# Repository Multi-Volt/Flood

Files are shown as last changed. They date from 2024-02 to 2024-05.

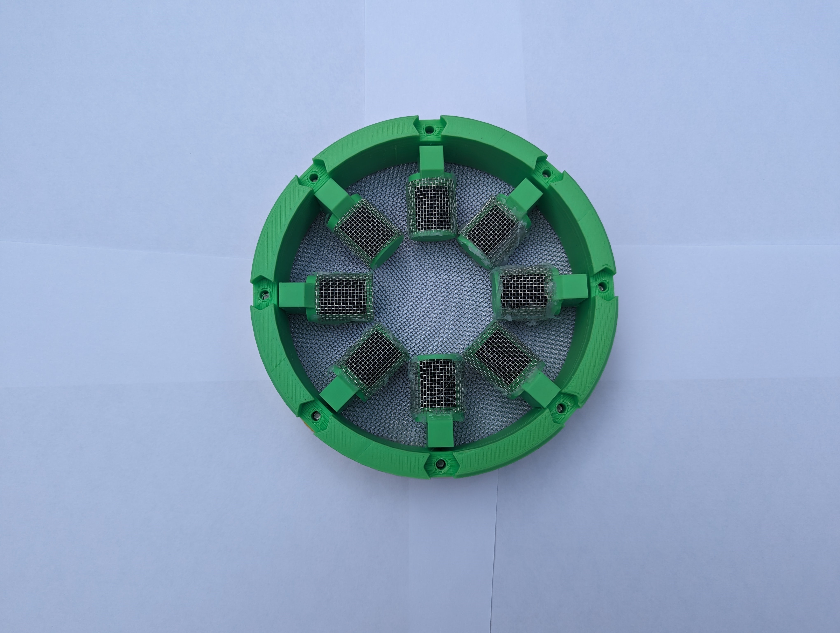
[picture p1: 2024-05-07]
FLOOD-Photos/Control/DesTopWheel.jpg

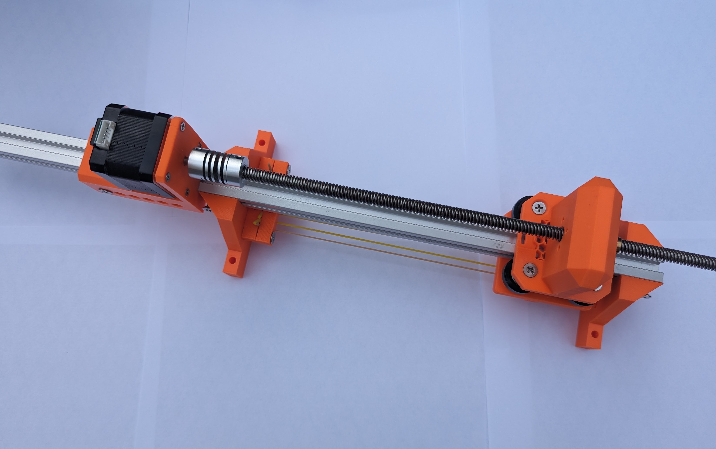
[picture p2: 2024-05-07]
FLOOD-Photos/Proto/NiTiTopView.jpg

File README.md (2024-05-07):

# Flood

[![Platform Io](https://img.shields.io/badge/build%20with-PlatformIO-orange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)](https://platformio.org/)

This research endeavor, conducted by __Dr. John LaRocco__, __Dr. Qudsia Tahmina__, and __John Simonis__ at The Ohio State University, is dedicated to the development of an Elastocaloric atmospheric water harvester. Specifically, the primary objective of this project is to construct a system that can be juxtaposed with a conventional desiccant wheel system for the purpose of energy efficient water harvesting. Included in this repository is the evaluation of the efficiency and effectiveness of the newly developed system in comparison to its traditional counterpart. This project is a significant and novel step towards innovative solutions in the field of water harvesting technology.
## Requirements
### Software
- [VSCode](https://code.visualstudio.com/Download)
- [Platform IO](https://platformio.org/)
- [Git](https://git-scm.com/downloads)
- [Arduino IDE](https://www.arduino.cc/en/software)
- [PySR](https://github.com/MilesCranmer/PySR)
- [PrusaSlicer]( https://www.prusa3d.com/en/page/prusaslicer_424/) or other slicer
### Hardware
- [FLOOD-BOM](https://github.com/Multi-Volt/Flood/tree/main/FLOOD-BOM/)
- 3D-Printer
- Screw Driver
# Table of contents
- [Models & Construction](#models)
- [Data](#data)
- [Datalogger](#datalogger)
- [Testing](#testing)
- [Flood Equations](#flood-equations)
- [Flood MCU](#flood-mcu)
- [Flood Photos](#flood-photos)
- [License](#license)
## Models & Construction
For this project, all pertinent 3D models are housed in the [FLOOD-3DF](https://github.com/Multi-Volt/Flood/tree/main/FLOOD-3DF) directory. This directory is organized into the following sub-directories for ease of navigation and access:
1. **Proto**: This contains both STEP and STL files of the final prototype.
2. **Control**: This includes the STEP and STL files for the Control Harvester.
3. **Deprecated**: This houses the STL files of designs that are no longer in use.
### Details
**Control Water Harvester Assembly Overview and Instructions**

The Control Water Harvester utilizes a desiccant wheel design, leveraging a heat lamp to dry out pockets of desiccant and a fan to circulate heated air through the silica gel desiccant. The assembly process is as follows:
1. **File Download**: Retrieve the STL files from [FLOOD-3DF](https://github.com/Multi-Volt/Flood/tree/main/FLOOD-3DF) and the .3MF file if you plan to print the design on a standard Ender 3 PRO.
2. **Setup**: Import the model or .3MF into an FDM 3D-Printer slicer such as [PrusaSlicer]( https://www.prusa3d.com/en/page/prusaslicer_424/) and select a material profile for PETG, which is necessary for higher temperatures.
3. **Slicing**: Configure a print with one wheel base and eight wheel rungs. Ensure the slicing settings include 100% infill, supports everywhere, and a layer height of 0.16mm or lower. Refer to the .3MF file for printing orientations
4. **Assembly**: Connect each of the rungs to the wheel base and secure each with M5 bolts and nuts, as specified in the Bill of Materials (BOM).
5. **Testing**: Upon completion of assembly, conduct a test using a lab power supply. Ensure the availability of fans and a heating device.

**NiTi Prototype Assembly Instructions**

The NiTi prototype employs a straightforward gantry system, powered by a high torque stepper motor. A T8 leadscrew is incorporated for a simple mechanical advantage to apply stress to the NiTi wires. The assembly process is as follows:
1. **File Download**: Retrieve the STL files from [FLOOD-3DF](https://github.com/Multi-Volt/Flood/tree/main/FLOOD-3DF) and the .3MF file if you plan to print the design on a standard Ender 3 PRO.
2. **Setup**: Import the model or .3MF into an FDM 3D-Printer slicer such as [PrusaSlicer]( https://www.prusa3d.com/en/page/prusaslicer_424/). Select a material profile for PETG, which is necessary for higher temperatures.
3. **Slicing**: Configure a print with one of each part, except for the anchors, of which you should print two. Ensure the slicing settings include 100% infill, supports everywhere, and a layer height of 0.16mm or lower. Refer to the .3MF file for printing orientations
4. **Nut Selection**: Based on the dimensions of most of the nut pockets, identify suitable metric nuts.
5. **Assembly**: Secure each of the items in accordance with the provided render.
6. **Gantry Fastening**: Ensure the use of the appropriate metric T-nuts for fastening to the supplied gantry.
7. **Testing**: Upon completion of the mechanical assembly, refer to the wiring diagram provided below and prepare for testing. You will need to either develop your own code for controlling the motors or utilize the open-source [GRBL](https://github.com/grbl/grbl) firmware.

[(Back to top)](#table-of-contents)
### Wiring

**Control Water Harvester**

The control water harvester uses one PC fan and a generic ~150-watt heat lamp. It is mounted to a piece of wood and turns with heated air blowing through each rung filled with desiccant on the wheel. For an example setup please see [FLOOD-Photos](https://github.com/Multi-Volt/Flood/tree/main/FLOOD-Photos). Water recorded was done using the sensor setup found in [FLOOD-Schematics](https://github.com/Multi-Volt/Flood/tree/main/FLOOD-Schematics).

**NiTi Water Harvester**

The NiTi water harvester uses a generic 8-amp DC barrel jack power supply. It can be mounted to a piece of wood and during testing was controlled with an Atmega328p microcontroller running the [GRBL](https://github.com/grbl/grbl) firmware. For an example setup please see [FLOOD-Photos](https://github.com/Multi-Volt/Flood/tree/main/FLOOD-Photos). Water recorded was done using the sensor setup found in [FLOOD-Schematics](https://github.com/Multi-Volt/Flood/tree/main/FLOOD-Schematics).

[(Back to top)](#table-of-contents)
## Data
Currently, all data for this project can be found within the [FLOOD-Data](https://github.com/Multi-Volt/Flood/tree/main/FLOOD-Data) folder. This folder currently contains:
- Control (XLSX)
- Prototype (XLSX)
- Analysis ([Jupyter Notebook](https://jupyter.org/))

[(Back to top)](#table-of-contents)
## Datalogger
This project currently uses a compiled Datalogger from a previous research project from this team. Currently, this binary is only compiled for Windows systems and is present within the [FLOOD-Datalogger](https://github.com/Multi-Volt/Flood/tree/main/FLOOD-Datalogger) folder.

[(Back to top)](#table-of-contents)
## Testing
**Project Testing Procedure**

The testing procedure for this project was executed with a straightforward approach. The following steps were undertaken:
- **Assemblies**: Both the prototype and control assemblies were positioned within an enclosure equipped with a continuously operating humidifier.
- **Data Gathering**: Data was systematically collected at regular intervals of 10 seconds. Measurements, such as current, were averaged over this time frame.
- **Noise Reduction**: The averaging of measurements over the specified time frame was implemented to effectively mitigate the impact of noise and potential outliers.
- **Execution**: A total of three tests were conducted for both the control and the prototype assemblies.
- **Duration**: The entire testing procedure was carried out over a cumulative duration of 30 minutes.
- **Water Sensor**: The resistive water sensor was calibrated using a control amount of water for precision before any water was harvested.
This methodical approach ensured a comprehensive evaluation of the project components under the specified conditions.

[(Back to top)](#table-of-contents)
## Flood Equations
These are equations fitted to the averaged data of each water harvester design. These equations were fitted using PySR and were designed to minimize the MSE between the two equations, if the Jupyter notebook file present in [FLOOD-Data](https://github.com/Multi-Volt/Flood/tree/main/FLOOD-Data/Analysis) is run again, each would have different results.

MSE:
```math
\text{MSE}=\frac{1}{n}\sum_{i=1}^{n}(f(x)-g(x))^{2}
```
Desiccant Control Wheel:
```math
\log{\left(1.18^{x + 0.841 \cos{\left(x^{0.974} + 0.155 \right)} + \cos{\left(\left\lceil{x}\right\rceil^{0.553} \right)} \left\lfloor{e^{\text{erf}{\left(x \right)}}}\right\rfloor} + 0.550 x \right)}
```
```math
\text{MSE}=2.695e-02
```
NiTi Prototype:
```math
x \left(- 0.000675 x - 0.00581 \cos{\left(0.861 \text{erf}{\left(\cos{\left(0.632 x \right)} \right)} + 0.861 \left\lfloor{x - 0.855}\right\rfloor \right)} + 0.214\right)
```
```math
\text{MSE}=2.507e-02
```
Deprecated Control:
```math
\left\lceil{\log{\left(0.526 x + 2.07 \right)}}\right\rceil \text{erf}{\left(0.0790 x + 0.0790 \sin{\left(0.0924 x \left\lfloor{x + \sin{\left(x \cos{\left(\cos{\left(\text{erf}{\left(\cos{\left(\left(e^{x} + 2.07\right) \left\lceil{\cos{\left(2 e^{\left\lceil{x}\right\rceil + 1} \right)}}\right\rceil \right)} \right)} \right)} \right)} \right)}}\right\rfloor \right)} \right)}
```
```math
\text{MSE}=8.403e-03
```
Deprecated Prototype:
```math
\log{\left(1.08^{x + 2.39 e^{\sin{\left(x + 0.573 \right)}}} \text{erf}{\left(\sin{\left(\text{erf}{\left(\cos{\left(1.07^{\left\lceil{x + 1.00 \cos{\left(x + 0.771 \right)} + 0.349}\right\rceil} \right)} \right)} \right)} \right)} + 1.14^{x} \right)}^{0.720}
```
```math
\text{MSE}=1.869e-02
```

## Flood MCU
**Instructions for Opening and Building MCU Code**

1. **Install Visual Studio Code (VS Code)**: Ensure that you have VS Code installed on your system as per the prerequisites mentioned earlier.
2. **Install Platform IO**: After successfully installing VS Code, proceed to install Platform IO.
3. **Download the Platform IO Directory**: Once Platform IO is installed, download the Platform IO directory from the [FLOOD-MCU](https://github.com/Multi-Volt/Flood/tree/main/FLOOD-MCU) folder.
4. **Open the Platform IO Directory in VS Code**: After downloading the files, open the directory in VS Code.
5. **Navigate to the Platform IO Extension**: Within VS Code, navigate to the Platform IO extension.
6. **Select the Folder**: From the Platform IO extension, choose the 'Pick a folder' option and select the folder that contains the `platformio.ini` file.
7. **Access the main.cpp Program**: You can now access the `main.cpp` program located in the `src` directory.
8. **Ensure Arduino Nano or Uno is Plugged In**: To access automatic build deployment, ensure that an Arduino Nano or Arduino Uno is plugged into your system.

[(Back to top)](#table-of-contents)
## Flood Photos
For this project, all pertinent images are housed in the [FLOOD-PHOTOS](https://github.com/Multi-Volt/Flood/tree/main/FLOOD-PHOTOS) directory. This directory is organized into the following sub-directories for ease of navigation and access:
1. **Proto**: This contains images for the final prototype.
2. **Control**: This includes images for the Control Harvester.
3. **Deprecated**: This houses the images for designs that are no longer in use.
# License
The MIT License (MIT) 2024 - [Dr. John LaRocco](https://github.com/javeharron/), [Dr. Qudsia Tahmina](https://github.com/tahminaq), [John Simonis](https://github.com/Multi-Volt/). Please have a look at the [LICENSE.md](LICENSE) for more details.

[(Back to top)](#table-of-contents)

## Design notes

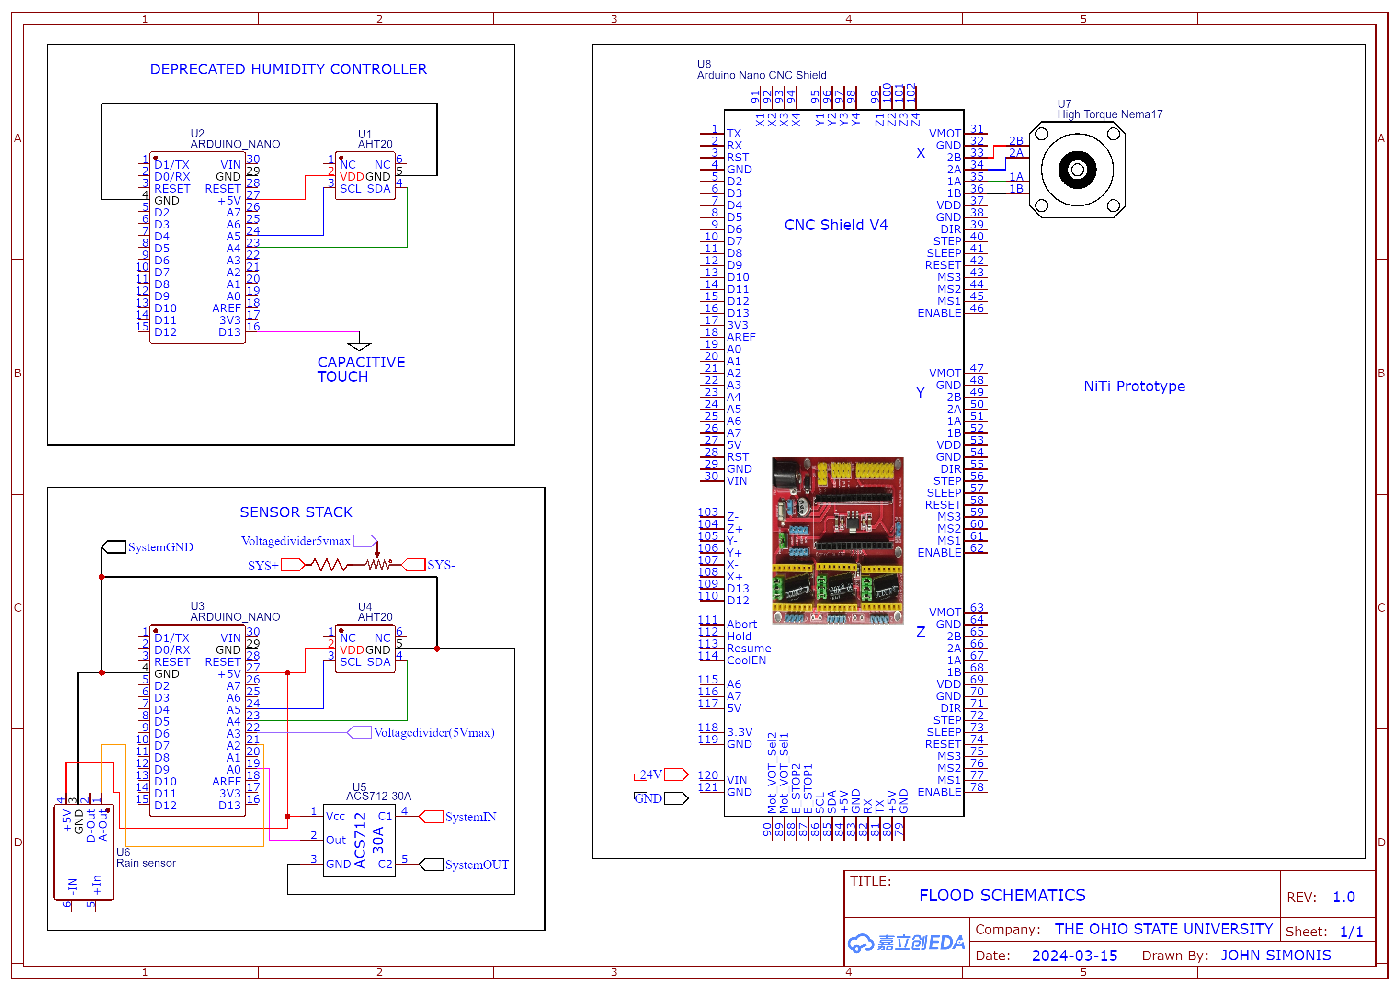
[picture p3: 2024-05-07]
FLOOD-Schematics/Schematics.png

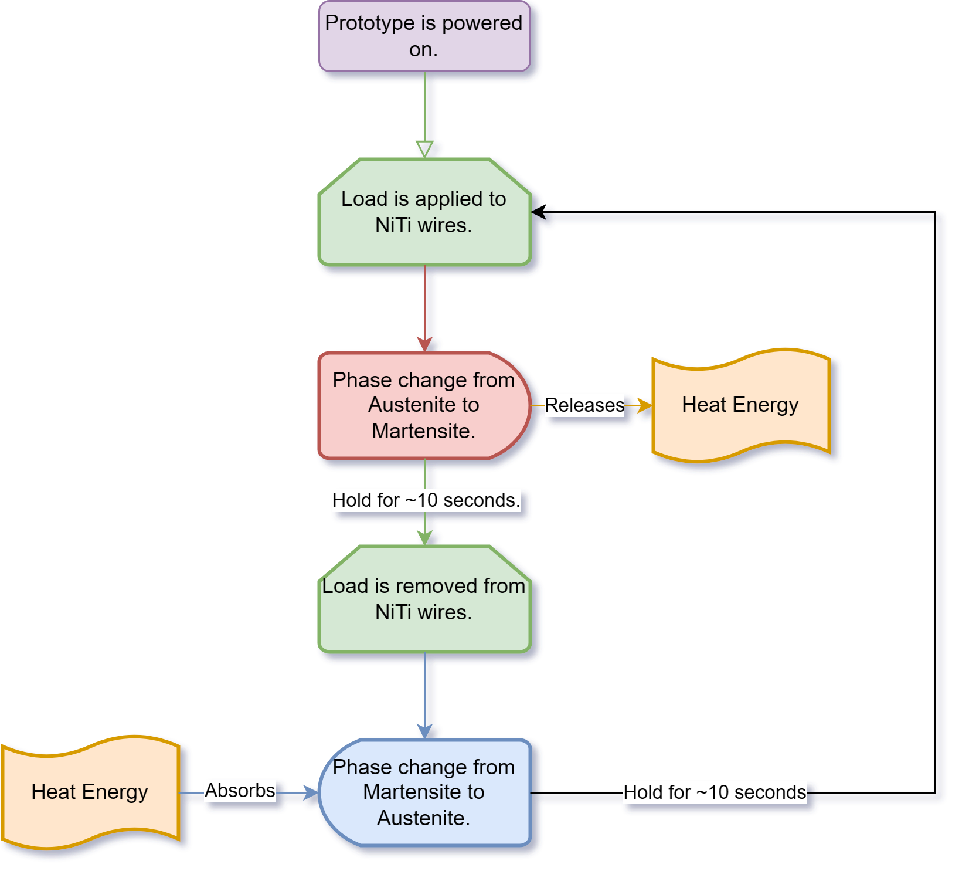
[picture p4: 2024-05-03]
FLOOD-Photos/Nitinol Process.png

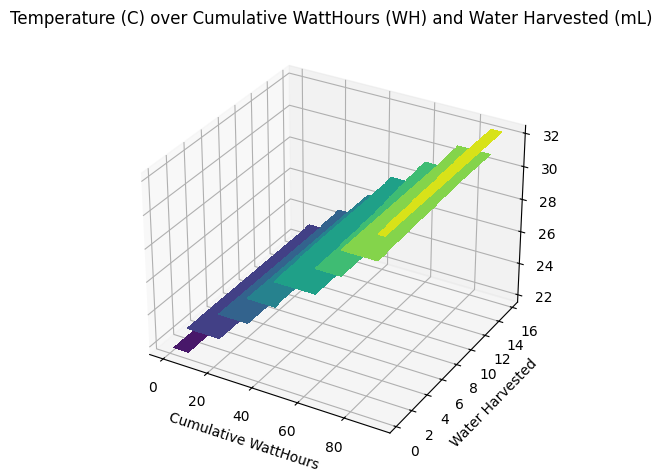
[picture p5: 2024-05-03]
FLOOD-Photos/Control/DesControlContour.png

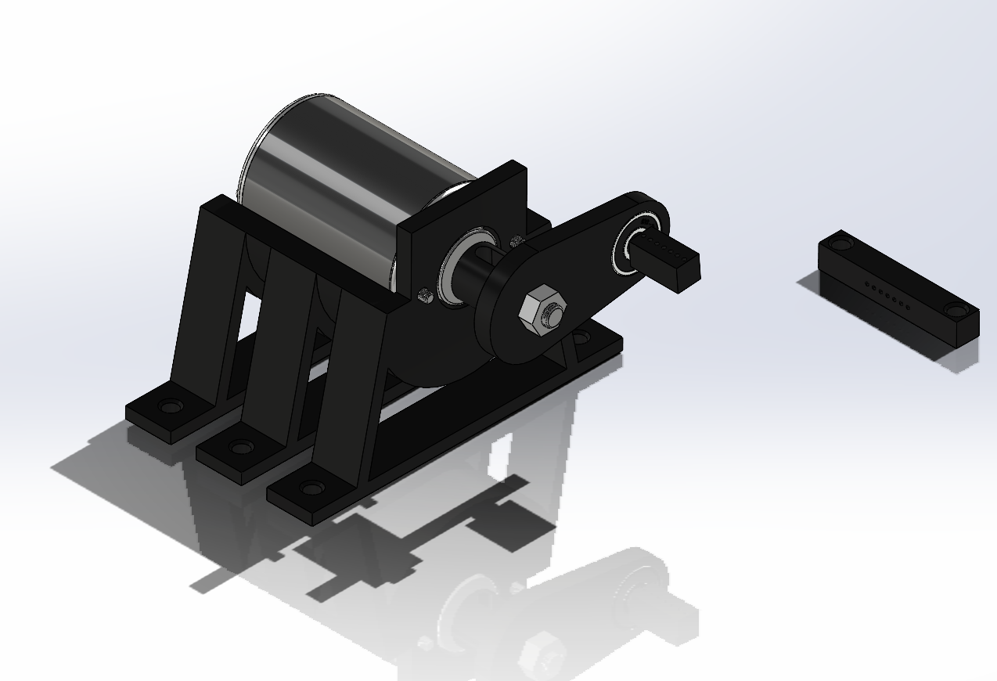
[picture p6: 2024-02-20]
FLOOD-Photos/Proto1_Render.png

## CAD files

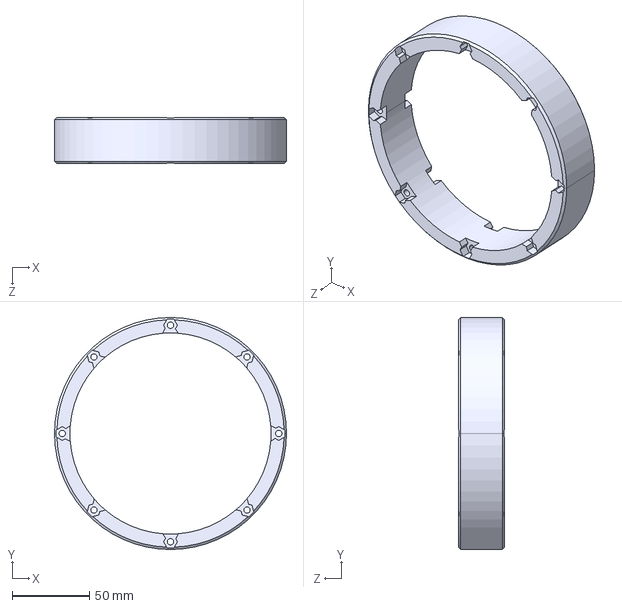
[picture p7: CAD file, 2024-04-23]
FLOOD-3DF/Control/CAD/CentralRing.STEP
150.0 x 150.0 x 30.0 mm

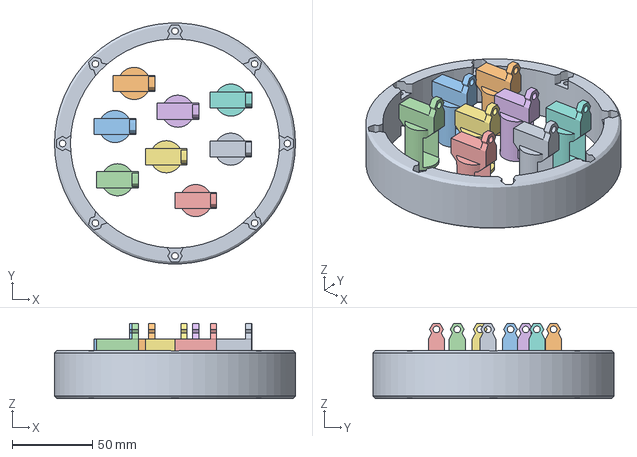
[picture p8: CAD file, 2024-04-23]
FLOOD-3DF/Control/Ender3_ControlPrintFile.3mf
150.0 x 149.8 x 46.8 mm
CentralRing.STL
WheelRung.STL x 8

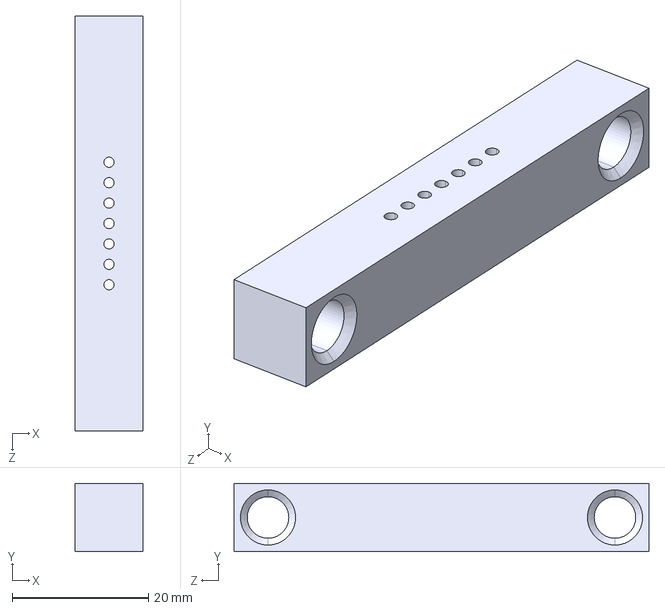
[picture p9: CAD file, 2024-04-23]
FLOOD-3DF/Proto/CAD/StaticAnchor.STEP
10.0 x 10.0 x 61.0 mm

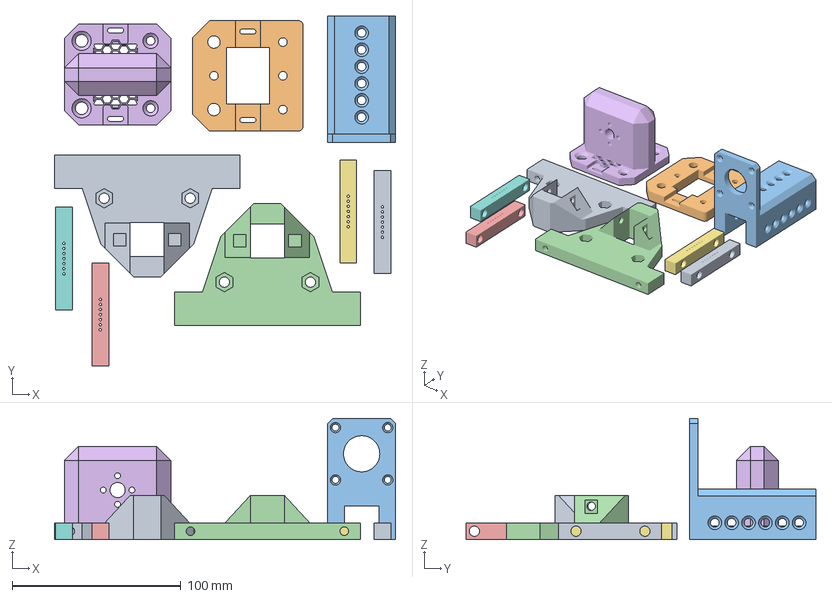
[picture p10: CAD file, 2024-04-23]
FLOOD-3DF/Proto/Ender3_ProtoPrintFile.3mf
202.4 x 207.5 x 71.9 mm
CarriageAnchor.STL x 2
CarriageSupportBracket.STL
MotorMount.STL
Stand.STL x 2
StaticAnchor.STL x 2
WheelCarriage.STL

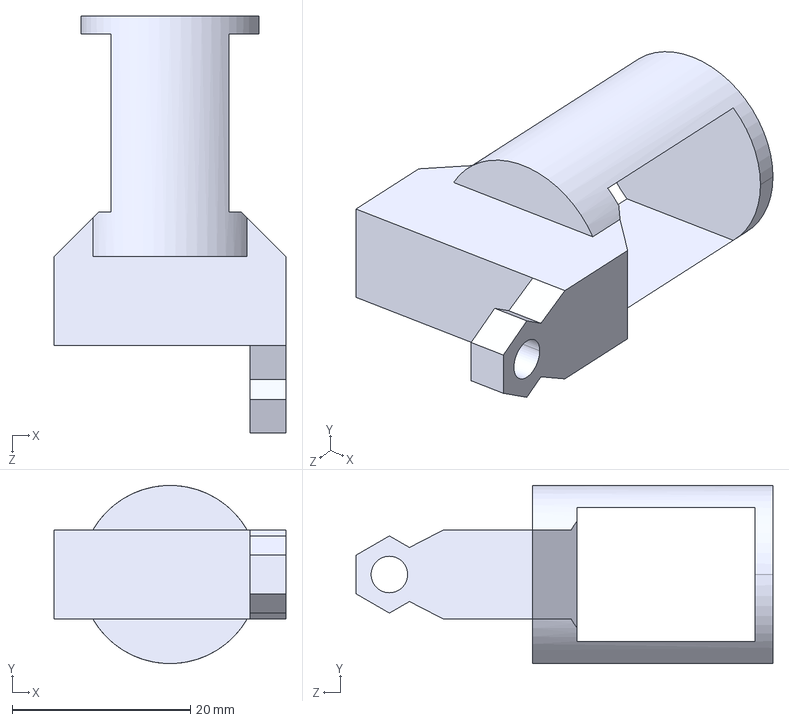
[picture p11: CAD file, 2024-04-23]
FLOOD-3DF/Control/CAD/WheelRung.STEP
26.0 x 20.0 x 46.8 mm

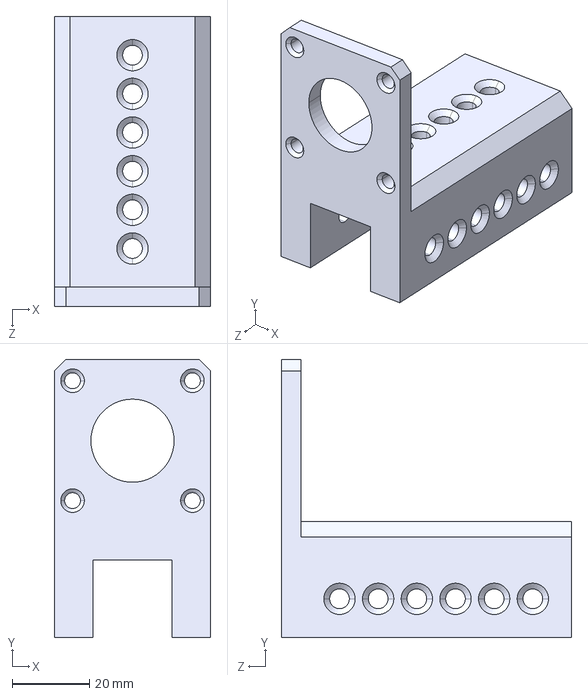
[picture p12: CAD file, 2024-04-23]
FLOOD-3DF/Proto/CAD/MotorMount.STEP
40.4 x 71.9 x 75.0 mm

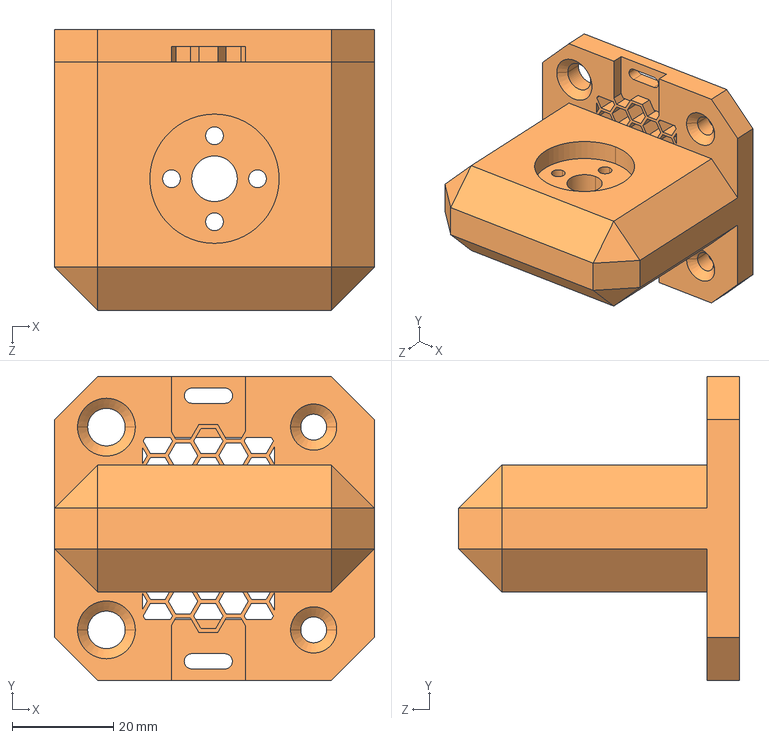
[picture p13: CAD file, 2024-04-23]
FLOOD-3DF/Proto/CAD/WheelCarriage.STEP
63.1 x 60.0 x 55.4 mm

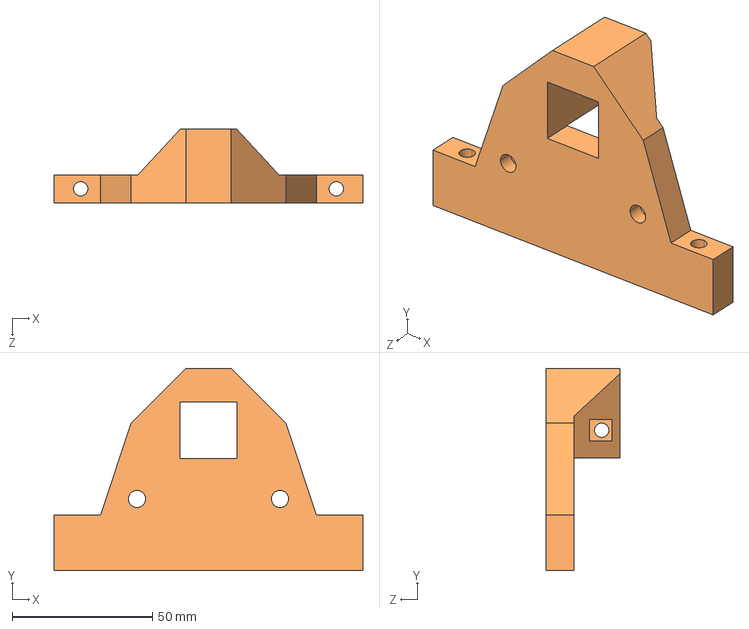
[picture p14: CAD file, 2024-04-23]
FLOOD-3DF/Proto/CAD/Stand.STEP
110.2 x 72.2 x 26.3 mm

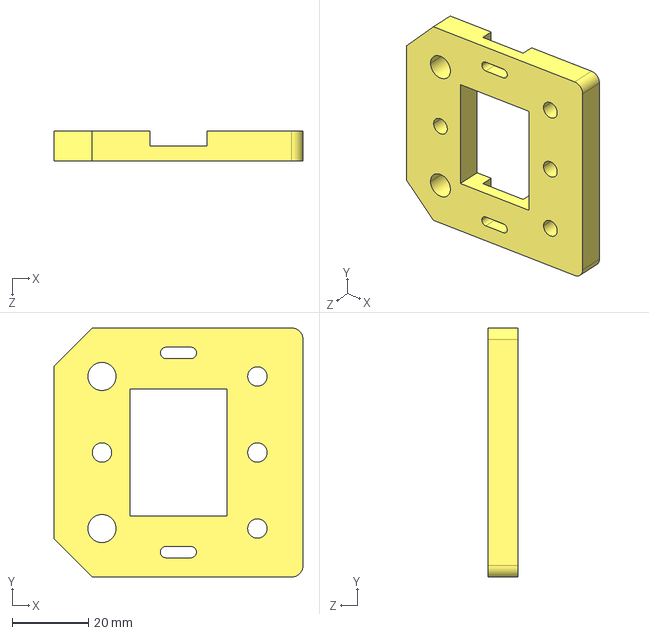
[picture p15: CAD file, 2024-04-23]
FLOOD-3DF/Proto/CAD/CarriageSupportBracket.STEP
65.5 x 65.5 x 8.00 mm

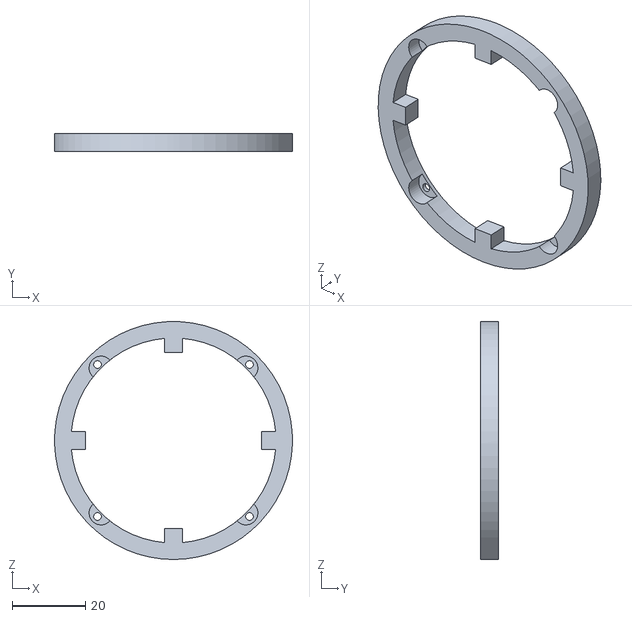
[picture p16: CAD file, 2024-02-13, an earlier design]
FLOOD-3DF/Deprecated/Control/Control_LidBracket.STL
65.0 x 5.00 x 65.0

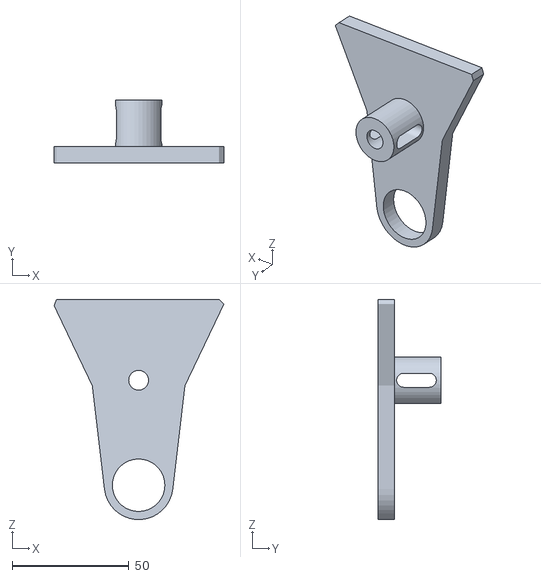
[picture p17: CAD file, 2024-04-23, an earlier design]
FLOOD-3DF/Deprecated/Prototype1_Rev2/Proto1_Cam.STL
72.7 x 27.0 x 94.3

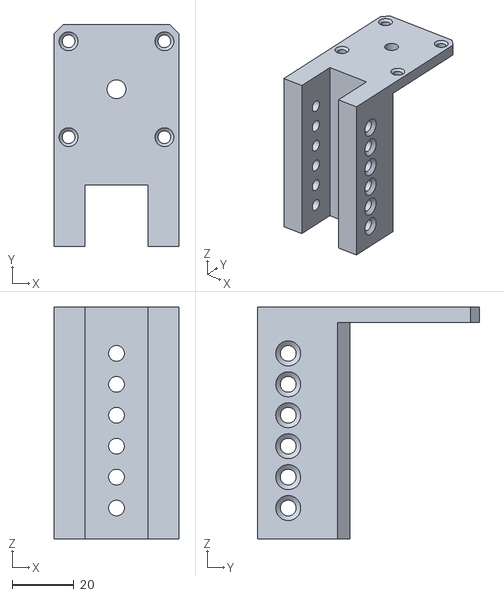
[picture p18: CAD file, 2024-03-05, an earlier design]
FLOOD-3DF/Deprecated/Prototype2/Proto2_MotorMount.STL
40.4 x 71.9 x 75.0

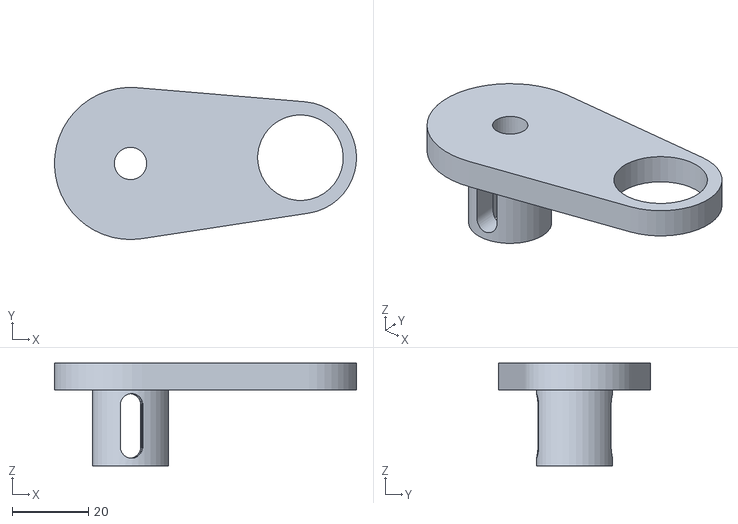
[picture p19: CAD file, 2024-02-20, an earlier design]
FLOOD-3DF/Deprecated/Prototype1_Rev1/Proto1_Cam.STL
79.4 x 40.0 x 27.0

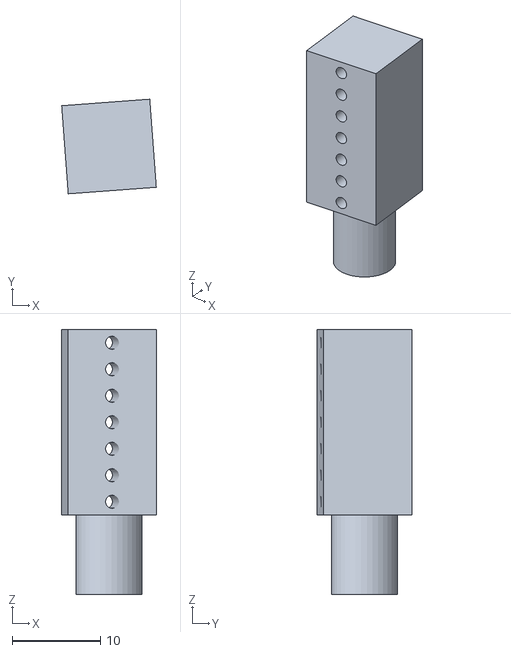
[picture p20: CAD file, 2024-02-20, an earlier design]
FLOOD-3DF/Deprecated/Prototype1_Rev2/Proto1_CamArm.STL
10.7 x 10.7 x 30.0

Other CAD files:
FLOOD-3DF/Proto/CAD/CarriageAnchor.STEP
FLOOD-3DF/Deprecated/Prototype1_Rev1/Proto1_StaticAnchor.STL
FLOOD-3DF/Deprecated/Prototype2/Proto2_CarriageTop.STL
FLOOD-3DF/Control/STL/CentralRing.STL
FLOOD-3DF/Control/STL/WheelRung.STL
FLOOD-3DF/Deprecated/Prototype1_Rev1/Proto1_MotorMount.STL
FLOOD-3DF/Deprecated/Prototype1_Rev2/Proto1_MotorMount.STL
FLOOD-3DF/Deprecated/Prototype1_Rev2/Proto1_StaticAnchor.STL
FLOOD-3DF/Deprecated/Prototype2/Proto2_CarriageAnchor.STL
FLOOD-3DF/Deprecated/Prototype2/Proto2_CarriageBottom.STL
FLOOD-3DF/Deprecated/Prototype2/Proto2_Stand.STL
FLOOD-3DF/Deprecated/Prototype2/Proto2_StaticAnchor.STL
FLOOD-3DF/Proto/STL/CarriageAnchor.STL
FLOOD-3DF/Proto/STL/CarriageSupportBracket.STL
FLOOD-3DF/Proto/STL/MotorMount.STL
FLOOD-3DF/Proto/STL/Stand.STL
FLOOD-3DF/Proto/STL/StaticAnchor.STL
FLOOD-3DF/Proto/STL/WheelCarriage.STL

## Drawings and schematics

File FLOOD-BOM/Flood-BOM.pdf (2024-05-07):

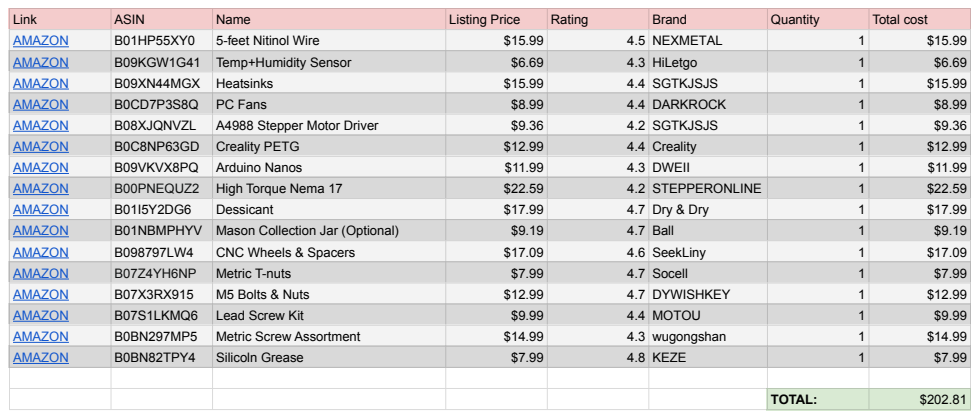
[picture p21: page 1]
Link; ASIN; Name; Listing Price; Rating; Brand; Quantity; Total cost; AMAZON; 5-feet Nitinol Wire; 4.5 NEXMETAL; B09KGW1G41; Temp+Humidity Sensor; 4.3 HiLetgo; B09XN44MGX; Heatsinks; 4.4 SGTKJSJS; PC Fans; 4.4 DARKROCK; B08XJQNVZL; A4988 Stepper Motor Driver; 4.2 SGTKJSJS; Creality PETG; 4.4 Creality; B09VKVX8PQ; Arduino Nanos; 4.3 DWEII; B00PNEQUZ2; High Torque Nema 17; 4.2 STEPPERONLINE; Dessicant; 4.7 Dry & Dry; B01NBMPHYV Mason Collection Jar (Optional); 4.7 Ball; CNC Wheels & Spacers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

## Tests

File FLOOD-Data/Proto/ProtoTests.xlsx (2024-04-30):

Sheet: PTest1
Amps (A) | Water Level (mL) | Volts (V) | WattHours (WH) | Temp (C) | Relative Humidity (%) | Cumulative WattHours (WH) | Time (s)
8.71 | 0.00 | 23.90 | 0.58 | 23.19 | 100.00 | 0.58 | 10
0.00 | 0.00 | 23.80 | 0.00 | 23.74 | 100.00 | 0.58 | 20
7.91 | 0.00 | 23.90 | 0.52 | 23.60 | 100.00 | 1.10 | 30
0.00 | 0.00 | 24.00 | 0.00 | 23.24 | 100.00 | 1.10 | 40
8.35 | 0.00 | 24.10 | 0.56 | 23.80 | 100.00 | 1.66 | 50
0.00 | 0.00 | 24.00 | 0.00 | 23.88 | 100.00 | 1.66 | 60
8.13 | 0.00 | 24.20 | 0.55 | 23.55 | 100.00 | 2.21 | 70
0.00 | 0.00 | 23.90 | 0.00 | 23.30 | 100.00 | 2.21 | 80
8.51 | 0.00 | 23.90 | 0.57 | 23.95 | 100.00 | 2.77 | 90
0.00 | 0.00 | 24.00 | 0.00 | 23.38 | 100.00 | 2.77 | 100
8.03 | 1.00 | 24.00 | 0.54 | 23.60 | 100.00 | 3.31 | 110
0.00 | 1.00 | 24.00 | 0.00 | 23.80 | 100.00 | 3.31 | 120
8.58 | 1.00 | 24.00 | 0.57 | 23.72 | 100.00 | 3.88 | 130
0.00 | 1.00 | 24.10 | 0.00 | 23.56 | 100.00 | 3.88 | 140
7.95 | 1.00 | 23.80 | 0.53 | 23.55 | 100.00 | 4.41 | 150
0.00 | 1.00 | 24.00 | 0.00 | 23.52 | 100.00 | 4.41 | 160
8.26 | 1.00 | 23.90 | 0.55 | 23.15 | 100.00 | 4.96 | 170
0.00 | 1.00 | 24.10 | 0.00 | 23.31 | 100.00 | 4.96 | 180
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

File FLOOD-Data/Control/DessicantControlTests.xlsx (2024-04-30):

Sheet: CTest1
Amps (A) | Water Level (mL) | Volts (V) | WattHours (WH) | Temp (C) | Relative Humidity (%) | Cumulative WattHours (WH) | Time (s)
7.64 | 1.00 | 24.00 | 0.51 | 21.81 | 100.00 | 0.51 | 10
7.67 | 1.00 | 24.10 | 0.51 | 22.04 | 100.00 | 1.02 | 20
7.65 | 1.00 | 24.00 | 0.51 | 22.09 | 100.00 | 1.53 | 30
7.72 | 1.00 | 24.10 | 0.52 | 22.10 | 100.00 | 2.05 | 40
7.64 | 1.00 | 24.10 | 0.51 | 22.14 | 100.00 | 2.56 | 50
7.74 | 1.00 | 23.90 | 0.51 | 22.16 | 100.00 | 3.08 | 60
7.65 | 1.00 | 24.10 | 0.51 | 22.23 | 100.00 | 3.59 | 70
7.76 | 1.00 | 24.10 | 0.52 | 22.26 | 100.00 | 4.11 | 80
7.65 | 1.00 | 24.10 | 0.51 | 22.26 | 100.00 | 4.62 | 90
7.65 | 1.00 | 23.90 | 0.51 | 22.33 | 100.00 | 5.13 | 100
7.77 | 2.00 | 24.00 | 0.52 | 22.33 | 100.00 | 5.64 | 110
7.71 | 2.00 | 24.10 | 0.52 | 22.37 | 100.00 | 6.16 | 120
7.67 | 2.00 | 24.00 | 0.51 | 22.42 | 100.00 | 6.67 | 130
7.67 | 2.00 | 24.00 | 0.51 | 22.48 | 100.00 | 7.18 | 140
7.72 | 2.00 | 23.90 | 0.51 | 22.49 | 100.00 | 7.70 | 150
7.73 | 2.00 | 23.80 | 0.51 | 22.51 | 100.00 | 8.21 | 160
7.64 | 2.00 | 24.10 | 0.51 | 22.63 | 100.00 | 8.72 | 170
7.72 | 2.00 | 24.10 | 0.52 | 22.90 | 100.00 | 9.23 | 180
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

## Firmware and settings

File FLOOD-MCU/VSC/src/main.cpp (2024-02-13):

// Copyright (c) 2023, John Simonis and The Ohio State University
// This code was written by John Simonis for a research project at The Ohio State University.

#include <Arduino.h> //Arduino platform library
#include <Wire.h>  //Standard Arduino Library
#include <AHT20.h> //Library for the AHT temperature and relative humidity sesnsor https://github.com/dvarrel/AHT20

#define Cap_Pin PORTB5 // Capacitive touch pin from port register
#define Port_Cap PORTB // Pins port register
#define Data_Dir DDRB //Pin data direction register more information here: https://www.microchip.com/en-us/product/ATMEGA328P

#define Increment 1000     // In Millis
#define Testing_Time 1     // In Minutes
#define Target_Humidity 60 // In RH%
AHT20 THSensor; //Temperature + Humidity sensor object

float time, temperature, humidity; //Testing Data

void flood(int level) //Flood function 
{
  for (int i = 0; i <= level * 2; i++) //This sets the intensity of the humidifier based on the 3 preprogrammed levels
  {
    Data_Dir = Data_Dir & ~(1 << Cap_Pin); //More efficient than pinmode, using simple bitwise math to turn OFF 5th binary digit
    delay(1000);
    Data_Dir = Data_Dir | (1 << Cap_Pin); //More effecient than pinmode, using simple bitwise math to turn ON 5th binary digit
    Port_Cap = Port_Cap & ~(1 << Cap_Pin); //More efficient than digitalwrite, using simple bitwise math to turn ON 5th binary digit
    delay(1000);
  }
  for (int q = 0; q <= 7 - level * 2; q++) //Residual levels to turn off humidifier
  {
    Data_Dir = Data_Dir & ~(1 << Cap_Pin);
    delay(100);
    Data_Dir = Data_Dir | (1 << Cap_Pin);
    Port_Cap = Port_Cap & ~(1 << Cap_Pin);
    delay(100);
  }
}

int main(void) //Main function
{
  init(); //Initializes important USB protocols on Arduino Nano as well as hardware timers
  Data_Dir = Data_Dir | (1 << Cap_Pin);
  Wire.begin(); //Begins wire foor I2C
  Serial.begin(57600);
  if (!THSensor.begin()) //Checks for our THSensor object
  {
    Serial.println("Fatal Program Error: No THSensor");
    while (true)
    {
    };
  }
  while (true) //Main program loop
  {
    while (Serial.available() == 0) //Waits for any serial input to start automatic testing sequence (use datalogger)
    {
    }
    bool input = Serial.readStringUntil('\n'); //Reads for string
    if (input)
    { // Upon serial input this sequence will begin
      time = 0;
      Serial.println("Temperature (C), Humidity (%RH), Time (s)"); //Creates test headers
      while (time <= Testing_Time * 60)
      {
        temperature = THSensor.getTemperature();
        humidity = THSensor.getHumidity();
        while (humidity < Target_Humidity) //Simple checking loop to adjust intensity of humidification
        {
          if (humidity < Target_Humidity - 10)
          {
            flood(3);
          }
          else if (humidity < Target_Humidity - 5)
          {
            flood(2);
          }
          else if (humidity < Target_Humidity)
          {
            flood(1);
          }
          humidity = THSensor.getHumidity();
        }
        Serial.println(String(temperature) + "," + String(humidity) + "," + String(time)); //Output sensor data every interval when desired humidity is met.
        time += (Increment / 1000); //Increment time for loop.
      }
    }
  }
}

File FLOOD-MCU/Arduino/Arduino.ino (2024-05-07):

// Copyright (c) 2023, John Simonis and The Ohio State University
// This code was written by John Simonis for a research project at The Ohio State University.

#include <ACS712XX.h> //Library for the ACS712XX current sensors https://github.com/ElectroRush4u/ACS712
#include <Wire.h> //Standard Arduino Library
#include <AHT20.h> //Library for the AHT temperature and relative humidity sesnsor https://github.com/dvarrel/AHT20
AHT20 aht20; //Temperature + Humidity sensor object
#define period1 10000 //Time period 1
#define period2 1000 //Time period 2
unsigned long time1; //Time collected 1
unsigned long time2; //Time collected 2
unsigned long lastmillis1 = 0; //Used for timers
unsigned long lastmillis2 = 0;
unsigned long comparative_moisture = 0; //This needs normalized after the fact in excel
unsigned long last_moisture = 0;
float curavg = 0; //Allows us to mitigate noise in current average
ACS712XX ACS712(ACS712_30A,A0);
void setup() {
  Serial.begin(9600);
  Wire.begin(); //Begins wire foor I2C
  float _offset = ACS712.autoCalibrate(); //Current calibration
  last_moisture = analogRead(A2); 
}

void loop() { 
  time1 = (lastmillis1 + period1);
  time2 = (lastmillis2 + period2);
  if (analogRead(A2)>last_moisture){
    comparative_moisture = analogRead(A2);
    last_moisture = comparative_moisture;
  }
  if (millis() >= time1){ 
    Serial.println(String(curavg) +","+String(comparative_moisture)+","+String(map(analogRead(A3),0,1024,0,25)) + String(curavg/10*0.00277778*24)+","+String(aht20.getTemperature())+","+String(aht20.getHumidity()));
    lastmillis1 = millis();
    curavg = 0;
  }
  if (millis() >= time2){
    curavg += ACS712.getDC();
    lastmillis2 = millis();
  }
}
